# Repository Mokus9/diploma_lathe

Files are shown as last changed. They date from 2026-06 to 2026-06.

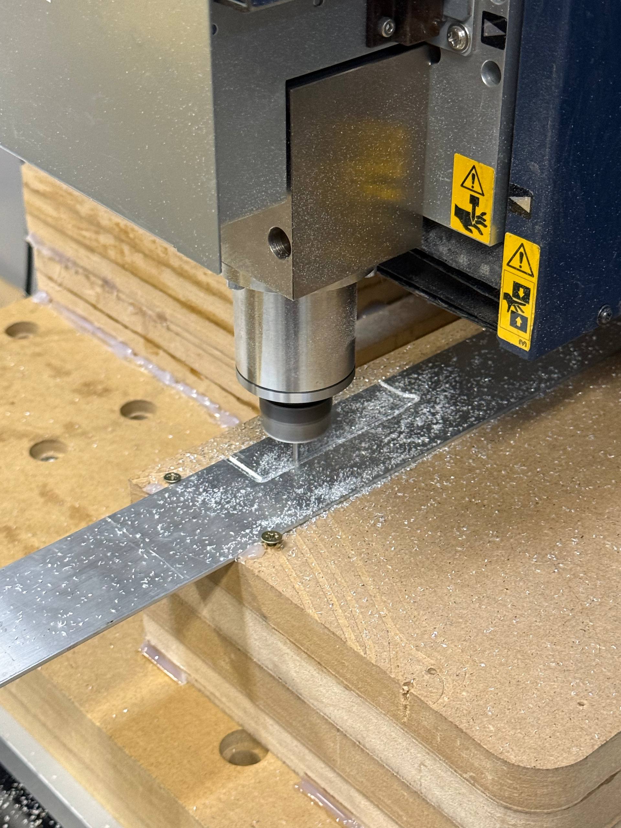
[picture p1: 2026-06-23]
photos/photo_2026-06-22_22-05-56.jpg

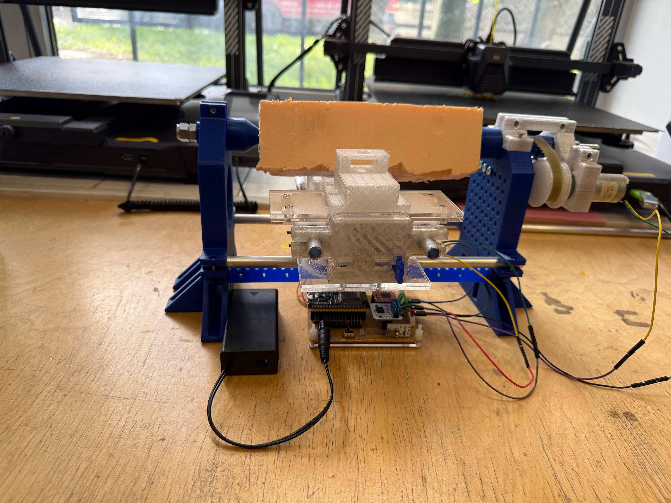
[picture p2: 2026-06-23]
photos/photo_2026-06-22_22-59-06.jpg

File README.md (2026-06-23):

# 🔧 Малогабаритный токарный станок с ЧПУ для детской мастерской




[]()
[]()

> Открытый проект малогабаритного токарного станка с элементами ЧПУ для обработки мягких материалов в условиях детской учебной мастерской. Вся конструкция воспроизводима на обычном бытовом 3D-принтере.

**Выпускная квалификационная работа магистра** | НИТУ МИСИС | 15.04.02 Технологические машины и оборудование | 2026

Автор: Шиков Максим Сергеевич  
Научный руководитель: Тавитов А.Г.

---

## 📸 Фотографии

> 📁 Все фотографии — в папке [`/photos`](/photos)

| Прототип в сборе | Шпиндельный узел | Изготовление резца |
|---|---|---|
||||

---

## 🎯 Зачем этот проект

Обработка резанием — историческая основа инженерного мышления — для младшей аудитории остаётся «за закрытой дверью»: настоящий токарный станок опасен (высокие обороты, сеть 220 В, разлетающаяся стружка). Существующие решения делятся на два полюса: уменьшенные «взрослые» станки, наследующие все опасности оригинала, и игрушки-имитации без реальной функции.

Этот станок закрывает незанятую нишу:

- ✅ Питание **7–12 В** от аккумулятора — сеть 220 В в рабочей зоне отсутствует полностью
- ✅ Обрабатывает **парафиновые свечи** — безопасно, доступно, наглядно
- ✅ Полностью **воспроизводим**: несущие детали печатаются на 3D-принтере
- ✅ Открытая система управления на **ESP32 + GRBL** — изучай и модифицируй
- ✅ Стандартный **G-код** — те же программы, что на взрослых станках
- ✅ **Себестоимость 4–6 тыс. ₽** — доступно для любого кружка или школы

---

## ⚙️ Технические характеристики

| Параметр | Значение |
|---|---|
| Ось X — расстояние между бабками | 140 мм |
| Ось Y — ход резцедержателя | 40 мм |
| Частота вращения шпинделя (макс.) | 915 об/мин |
| Рекомендуемый рабочий диапазон | 400–700 об/мин |
| Дискретность перемещения | 0,01 мм |
| Погрешность позиционирования | ±0,05 мм |
| Напряжение питания | 7–12 В DC (аккумулятор) |
| Материал несущих деталей | PETG (3D-печать FDM) |
| Направляющие | Алюминиевые трубки Ø10 мм |
| Линейные подшипники | Печатные из PETG |
| Привод шпинделя | DC 12В, ременная передача GT2 |
| Управление осями | ESP32 + TB6612FNG |
| Вал шпинделя | Стандартный болт с конусом |
| Подшипники | 608 (2 шт. в шпиндельном узле) |
| Защитный кожух | Прозрачный поликарбонат 3 мм |
| Основной материал обработки | Парафиновые свечи |

---

## 🗂️ Структура репозитория

```
/
├── README.md                   # Документация (русский)
├── README_EN.md                # Documentation (English)
├── LICENSE                     # Лицензия MIT
│
├── cad/                        # 3D-модели
│   └── lathe_v1.3dm            # Полная сборка (Rhino 3D)
│
├── stl/                        # STL-файлы для печати
│   ├── spindle_body.stl        # Корпус шпиндельного узла
│   ├── front_cone.stl          # Передний конус (зажимной)
│   ├── rear_cone.stl           # Задний конус (вращающийся центр)
│   ├── carriage.stl            # Платформа резцедержателя
│   ├── linear_bearing.stl      # Печатный линейный подшипник
│   ├── tool_holder.stl         # Резцедержатель
│   ├── frame.stl               # Рамная станина
│   └── cover_posts.stl         # Стойки защитного кожуха
│
├── firmware/                   # Прошивка ESP32
│   └── firmware_setup.md       # Инструкция по прошивке
│
├── electronics/                # Электроника
│   ├── schematic.pdf           # Принципиальная схема
│   └── bom_electronics.md      # Перечень компонентов
│
├── docs/                       # Документация
│   ├── assembly.md             # Пошаговая сборка
│   └── safety.md               # Требования безопасности
│
└── photos/                     # Фотографии
    ├── overview/               # Прототип в сборе
    ├── spindle/                # Шпиндельный узел
    └── toolmaking/             # Изготовление резца (фрезеровка)
```

---

## 🛒 Список комплектующих (BOM)

### Покупные компоненты

| # | Наименование | Кол-во | Цена, ₽ |
|---|---|---|---|
| 1 | Шаговые двигатели NEMA17 | 2 шт. | 600 |
| 2 | Двигатель DC 12В ~915 об/мин | 1 шт. | 400 |
| 3 | ESP32 + самодельная плата | 1 шт. | 350 |
| 4 | Драйвер TB6612FNG | 1 шт. | (в плату) |
| 5 | ШИМ-регулятор + кнопки | 1 компл. | 350 |
| 6 | Аккумулятор 7–12 В | 1 шт. | 600 |
| 7 | Алюминиевые трубки Ø10 мм | 1 м | 150 |
| 8 | Подшипники 608 | 4 шт. | (в 320) |
| 9 | Крепёж M3–M4, подшипники | комплект | 320 |
| 10 | Поликарбонат прозрачный 3 мм | 1 лист | 200 |
| 11 | Ремень GT2 + шкивы | 1 компл. | (в крепёж) |
| 12 | Филамент PETG | ~1 кг | 1 800 |

**Итого: ~4 000–6 000 ₽**  
**Замена одного печатного узла: 90–180 ₽** (перепечатка детали 50–100 г)

---

## 🖨️ Параметры 3D-печати

Все несущие детали — из **PETG**. Рекомендуемые настройки:

| Параметр | Значение |
|---|---|
| Температура сопла | 230–245 °С |
| Температура стола | 70–85 °С |
| Высота слоя | 0,2 мм |
| Заполнение | 40–60 % |
| Тип заполнения | Сетка / гироид |
| Скорость печати | 40–60 мм/с |
| Периметры | 3–4 |
| Охлаждение | 20–50 % |
| Поддержки | Минимальные |

> ⚠️ **Корпус шпиндельного узла** печатать вертикально — ось посадок подшипников 608 должна совпадать с направлением наплавления слоёв.

---

## 🔌 Система управления

### Архитектура (три независимых контура)

```

          ▼  Wi-Fi (без кабеля)
      [ESP32]
      │      │
      │      ▼
      │  [TB6612FNG] ──► [NEMA17 · ось X]
      │  [TB6612FNG] ──► [NEMA17 · ось Y]
      │
      └──► [ШИМ] ──► [DC Motor 12В · шпиндель]

[Кнопка аварийного стопа] ──► разрыв питания всех контуров
```

- **Контур 1 · Оси X/Y:** ESP32 → TB6612FNG → шаговые двигатели
- **Контур 2 · Шпиндель:** DC 12В через ШИМ — плавная регулировка оборотов
- **Контур 3 · Аварийный стоп:** кнопка отключает всё одновременно

### Быстрый старт

```bash
# 1. Клонировать репозиторий
git clone https://github.com/m112521/mini-cnc-lathe.git

# 2. Открыть в Arduino IDE
# Файл: firmware/main.ino

# 3. Установить поддержку ESP32
# Boards Manager → esp32 by Espressif Systems

# 4. Выбрать плату ESP32 Dev Module, порт → Upload
```

Подробно: [`firmware/firmware_setup.md`](firmware/firmware_setup.md)

---

## 🔨 Сборка (9 этапов)

Полная инструкция: [`docs/assembly.md`](docs/assembly.md)

1. Распечатать все детали из PETG
2. Запрессовать подшипники 608 в корпус шпиндельного узла
3. Собрать шпиндель: болт → конус → шкив GT2
4. Собрать станину: алюминиевые трубки в опоры, проверить параллельность
5. Установить ходовые винты и шаговые двигатели
6. Установить заднюю бабку (конус на подшипнике)
7. Смонтировать платформу резцедержателя на печатных подшипниках
8. Подключить электронику по схеме, установить кожух из поликарбоната
9. Залить прошивку, откалибровать оси, установить Home

---

## 🪚 Резец

Резец изготовлен вручную — **фрезерование из быстрорежущей стали (HSS)**. Фотографии процесса: [`/photos/toolmaking`](/photos/toolmaking).

> Для парафина и воска подходит любой резец с большим передним углом — усилия резания измеряются единицами ньютонов.

---

## 🛡️ Безопасность

Нормативная база: **ГОСТ 28139-89** и **ГОСТ Р «Оборудование учебное»** (с июня 2026).  
Новый стандарт устанавливает **7–12 В** как допустимое напряжение для начальной школы — станок соответствует.

| Категория | Меры |
|---|---|
| Механическая | Обороты ≤ 915 об/мин · поликарбонатный кожух 3 мм · кнопка аварийного стопа |
| Электрическая | Питание 7–12 В DC · нет 220 В · нет открытых контактов |
| Пожарная | Нет нагревателей · PETG и поликарбонат не воспламеняемы · крошка безопасна |
| Эргономическая | Шум ≤ 60 дБ · обзор через кожух · ремень гасит вибрацию |

---

## 🎓 Педагогические сценарии

| Уровень | Что делает ребёнок |
|---|---|
| Начальный | Запускает готовую программу, наблюдает за обработкой |
| Средний | Изменяет параметры G-кода, оценивает результат |
| Продвинутый | Пишет собственные программы, изучает прошивку ESP32 |
| Проектный | Печатает детали и собирает станок самостоятельно |

**Типичные учебные изделия из парафиновой свечи:** цилиндры и шары, шахматные фигуры, миниатюрные вазы, «ступенчатый вал», «конус».

---

## 📄 Лицензия

**MIT** — свободно использовать, копировать, модифицировать, в том числе в образовательных учреждениях.  
См. файл [LICENSE](LICENSE).

---

## 📬 Контакт

Максим Шиков — НИТУ МИСИС, 2026  
[Issues](../../issues) · [Pull Requests](../../pulls)

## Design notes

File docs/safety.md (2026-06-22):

# 🛡️ Требования безопасности

## Нормативная база

- **ГОСТ 28139-89** «Оборудование школьное. Общие требования безопасности»
- **ГОСТ Р «Оборудование учебное. Общие требования безопасности»** (с июня 2026)

Новый стандарт 2026 года устанавливает **7–12 В** как допустимое напряжение для оборудования начальной школы — данный станок соответствует этому требованию.

---

## Меры безопасности в конструкции

### ⚡ Электрическая
- Питание **7–12 В DC** от аккумулятора
- Сетевое напряжение 220 В **отсутствует** в рабочей зоне
- Силовые каналы защищены предохранителями
- Все соединения изолированы

### ⚙️ Механическая
- Все вращающиеся части закрыты **прозрачным кожухом из поликарбоната 3 мм**
- **Кнопка аварийного останова** (красная, грибовидная) разрывает все цепи одновременно
- Обороты ≤ 915 об/мин — кинетическая энергия вращающихся частей пренебрежимо мала
- Зазор между шпинделем и корпусом исключает захват одежды

### 🔥 Пожарная
- Нет нагревательных элементов в рабочей зоне
- PETG и поликарбонат не воспламеняются при нормальной эксплуатации
- Парафиновая крошка пожароопасности не представляет

### 👁️ Эргономическая
- Прозрачный кожух — процесс виден, доступ к деталям закрыт
- Уровень шума ≤ 60 дБ (ременная передача гасит вибрацию)
- Нет полостей, где скапливается парафиновая крошка

---

## Правила эксплуатации

### Перед работой
- [ ] Защитный кожух установлен и закрыт
- [ ] Заготовка надёжно зажата между конусами
- [ ] Кнопка аварийного останова исправна (проверить нажатием)
- [ ] В рабочей зоне нет посторонних предметов

### Во время работы
- Не открывать кожух при вращающемся шпинделе
- Не касаться заготовки и инструмента руками при вращении
- При любых сомнениях — нажать кнопку аварийного останова
- Не оставлять станок без присмотра

### После работы
- Выключить питание
- Убрать парафиновую крошку щёткой или пылесосом
- Хранить в защищённом от влаги месте

---

## Для педагогов

- Первое занятие — только под руководством взрослого
- Объяснить назначение кнопки аварийного останова **до** включения
- Убедиться, что волосы убраны, свободная одежда заправлена
- Рекомендуется использование **защитных очков**
- Нетоксичные материалы (PETG, поликарбонат, алюминий, парафин) безопасны при контакте

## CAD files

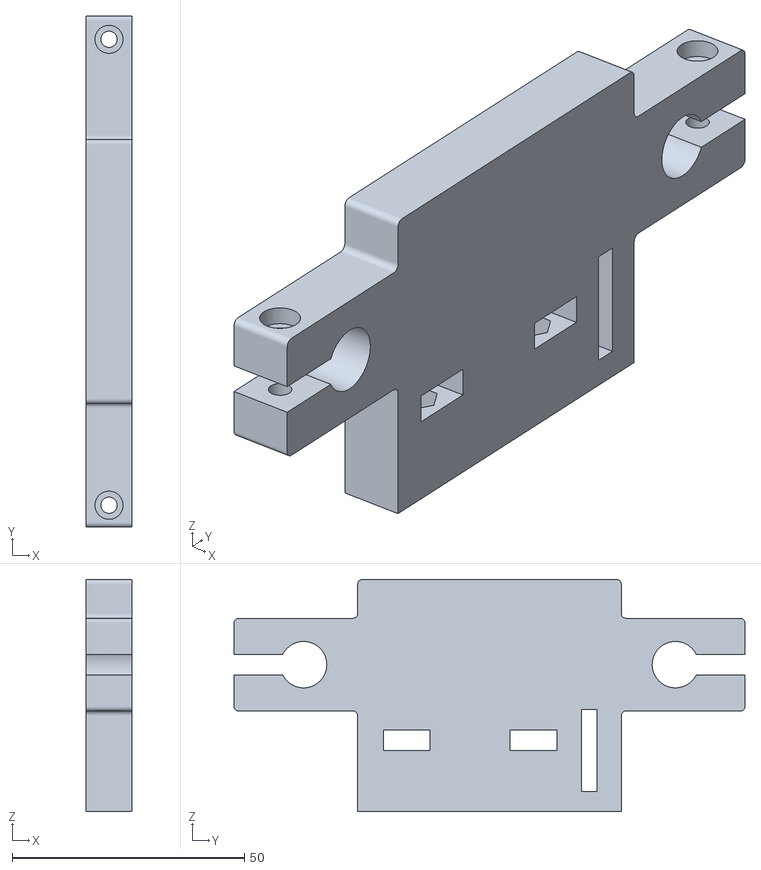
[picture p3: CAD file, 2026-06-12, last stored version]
leftwall.stl
10.0 x 110.1 x 50.0

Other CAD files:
rightwall.stl

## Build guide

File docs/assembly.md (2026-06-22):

# 🔨 Инструкция по сборке — 9 этапов

## Инструменты

- Шестигранники M3, M4
- Отвёртка крестовая
- Штангенциркуль
- Строительный фен (для запрессовки подшипников)
- Ножницы / нож (для поликарбоната)

---

## Этап 1 — Печать деталей

Распечатать все файлы из `/stl/` по настройкам из README. Удалить поддержки, зачистить посадочные поверхности. Подшипник 608 должен входить с лёгким натягом — если тугой, прогреть посадку феном до ~60°C.

---

## Этап 2 — Шпиндельный узел

```
[Передний конус] — [головка болта (вал)] — [подшипник 608] — [шкив GT2] — [подшипник 608] — [гайка]
```

1. Запрессовать два подшипника 608 в корпус передней бабки
2. Вставить болт через оба подшипника — он является валом шпинделя
3. Надеть и зафиксировать шкив GT2
4. Надеть передний конус на шестигранную головку болта (шестигранник исключает проворот)
5. Проверить плавность вращения

---

## Этап 3 — Задняя бабка

1. Запрессовать подшипник 608 в корпус задней бабки
2. Установить конус — он свободно вращается вместе с заготовкой (критично для мягкого парафина)

---

## Этап 4 — Станина и направляющие

1. Нарезать алюминиевые трубки Ø10 мм по длине
2. Установить в опоры станины, зафиксировать винтами M4
3. Проверить параллельность штангенциркулем в трёх точках — допуск ≤0,2 мм
4. Установить переднюю и заднюю бабки по концам

---

## Этап 5 — Ходовые винты и приводы

1. Установить ходовые винты осей X и Y
2. Закрепить шаговые двигатели NEMA17
3. Проверить плавность хода руками до подключения питания

---

## Этап 6 — Платформа резцедержателя

1. Надеть печатные линейные подшипники на направляющие трубки
2. Установить платформу, подключить к гайкам ходовых винтов
3. Проверить ход по обеим осям — не должно быть заеданий

> Не перетягивать крепёж подшипников — перекос ухудшает ход.

---

## Этап 7 — Ременная передача

1. Надеть ремень GT2 на шкив шпинделя и шкив двигателя
2. Отрегулировать натяжение: ремень натянут, но не перетянут
3. Проверить соосность шкивов

---

## Этап 8 — Электроника и кожух

Собрать по схеме [`/electronics/schematic.pdf`](/electronics/schematic.pdf):

1. Подключить шаговые двигатели к TB6612FNG
2. Подключить двигатель шпинделя через ШИМ к ESP32
3. Подключить кнопку аварийного останова в разрыв питания
4. Закрепить плату, убрать провода от движущихся частей
5. Установить кожух из поликарбоната 3 мм на печатные стойки
6. Убедиться, что кожух закрывает шпиндель и ременную передачу

---

## Этап 9 — Прошивка и калибровка

1. Залить прошивку (см. [`firmware/firmware_setup.md`](../firmware/firmware_setup.md))
2. Подключить к управляющей программе (Candle, UGS или аналог)
3. Проверить направление осей — при необходимости инвертировать в прошивке
4. Установить начальную точку Home
5. Тестовый ход 10 мм по каждой оси → проверить штангенциркулем

---

## Первый запуск

1. Зажать парафиновую свечу между конусами передней и задней бабок
2. Включить шпиндель, выставить ~400–500 об/мин
3. Загрузить тестовый G-код из [`/docs/gcode_examples/`](gcode_examples/)
4. Ожидаемый результат: чистая цилиндрическая поверхность без следов оплавления

---

## Типовые проблемы

| Проблема | Причина | Решение |
|---|---|---|
| Каретка движется рывками | Перетянуты подшипники | Ослабить крепёж |
| Парафин оплавляется | Высокие обороты + малая подача | Снизить до 400–500 об/мин |
| Двигатель пропускает шаги | Недостаточный ток | Увеличить ток в драйвере |
| Биение заготовки | Конусы несоосны | Выверить соосность бабок |
| Плохое качество поверхности | Люфт в ходовом винте | Подтянуть гайку винта |

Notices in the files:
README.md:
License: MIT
